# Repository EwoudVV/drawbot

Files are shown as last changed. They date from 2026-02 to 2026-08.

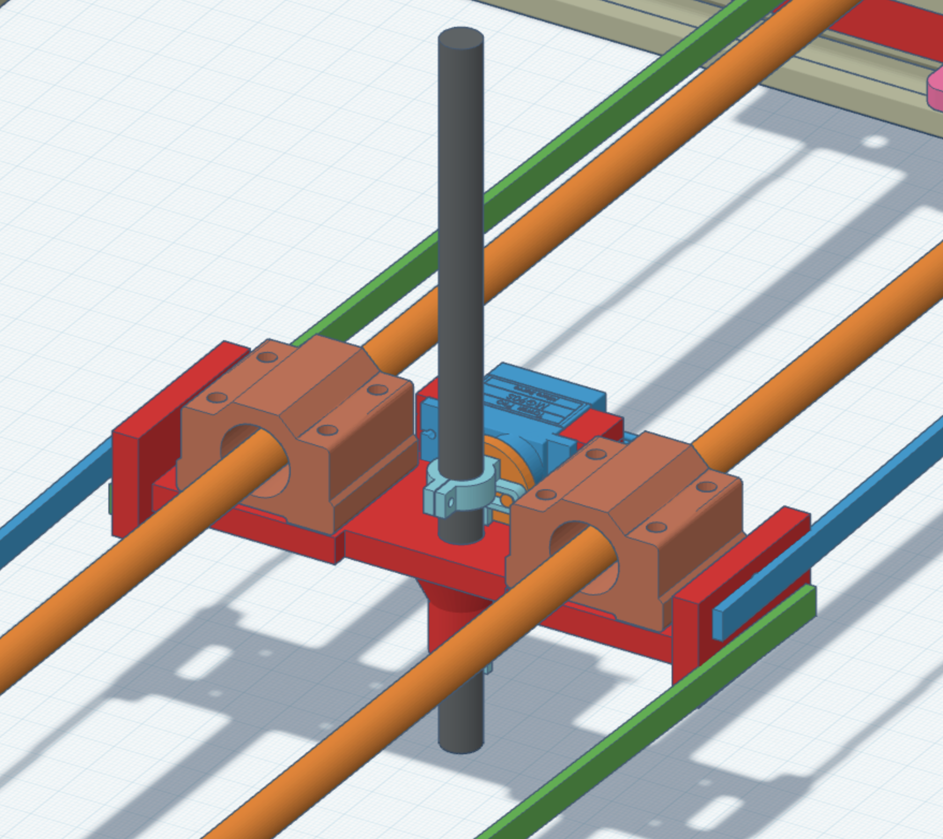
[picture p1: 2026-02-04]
pictures/toolhead.png

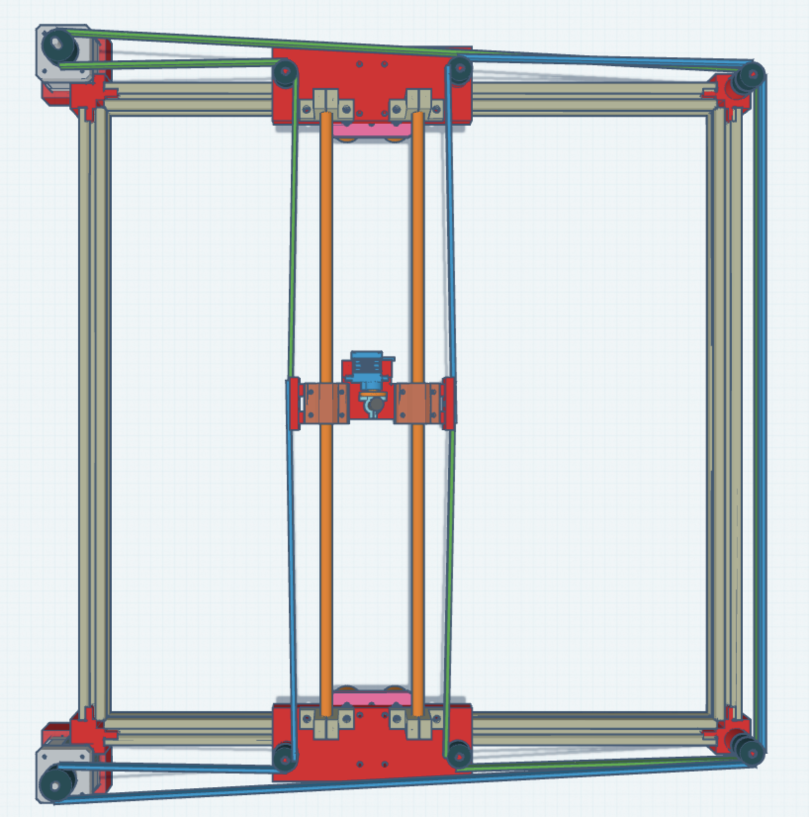
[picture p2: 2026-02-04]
pictures/topviewpersp.png

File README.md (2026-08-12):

## Drawbot

### Design: https://www.tinkercad.com/things/kSLyTMIcY53-drawbot

 - Made for [Hack Club Highway](https://highway.hackclub.com/)
 - This project is a 0.5 meter square drawing machine that I designed to be as fast and cheap as possible.
 - I made this project because I wanted to learn more about designing and using mechanisms, like the CoreXY belt design I used and the scotch-yoke mechanism used to lift the pen. I also wanted something functional, that I would use.

### Pictures



### Bill Of Materials

|Part |Qty|Price |Desc |Notes |Link |
|---|---|---|---|---|---|
|Arduino |1  |$29.30 |Uno R3 |not going to buy |http://store.arduino.cc/collections/boards-modules/products/arduino-uno-rev3 |
|Pen |60 |$7.99 |Bic Round Stic |not going to buy |https://us.bic.com/en_us/bic-round-stic-xtra-life-ball-point-pen-black-60-pack.html |
|500mm Aluminium Extrusion  |4  |$25.99 |500m V-slot aluminum extrusions |They come with extra accessories like connectors |https://www.amazon.com/Seekliny-Aluminum-Extrusion-V-Slotted-Accessories/dp/B0DY7FKXZ9/  |
|Linear Motion Rod Shaft |2  |$29.99 |Linear shaft for the toolhead to move on |Comes with bearings for the toolhead |https://www.amazon.com/uxcell-Bearing-Support-Automated-Machines/dp/B0CK4Z3M15 |
|Stepper Motor Nema 17 |2  |$25.99 |Motors to drive the gantry |High torque and high speed |https://www.amazon.com/Stepper-Motor-Bipolar-64oz-Printer/dp/B00PNEQI7W |
|Timing Belt |1  |$14.99 |5m belt |Extra accessories included like driver and idler wheels and belt clamps and tensioners|https://www.amazon.com/KeeYees-Timing-Tensioner-Torsion-Printer/dp/B07JKT5BZQ |
|Stepper Motor Driver Module|2  |$7.59 |Stepper motor drivers | |https://www.amazon.com/Stepper-Printer-StepStick-Envistia-Mall/dp/B07QT7N3T2 |
|Servo |1  |$2.99 |Fast servo that has metal gears and is small | |https://speedyfpv.com/products/mg90d-metal-digital-servo-new?variant=45194443030742 |
|Limit switches |2  |$5.56 |SS-5GL02 |For homing the toolhead |https://www.digikey.com/en/products/detail/omron-electronics-inc-emc-div/SS-5GL02/3102937|
|Roller plate |2  |$11.97 |Roller plates for attachment on the aluminum extrusions|Adjustable |https://www.amazon.com/QWORK-V-Wheel-Aluminum-Profile-Printer/dp/B0CHRYLV1V |
|Belt idler wheels |5  |$7.99 |Idler wheels for when the belt turns |4 extra are needed |https://www.amazon.com/Timing-Belt-Idler-Pulley-Printer/dp/B0BSPCHTD3 |
| | |SUBTOTAL: $133.06 |no extras | | |
| | |TOTAL: $141.38 |no extras and tax |assumes MA sales tax | |
| | |GRAND TOTAL: $170.35 |extras | | |
| | |GRAND GRAND TOTAL: $181.00|extras and tax |assumes MA sales tax | |

### Alternate BOM

|Part |Qty|Price |Desc |Notes |Link |
|---|---|---|---|---|---|
|Arduino |1  |$29.30 |Uno R3 |not going to buy | |
|Pen |60 |$7.99 |Bic Round Stic |not going to buy | |
|500mm Aluminium Extrusion  |4  |$25.99 |500m V-slot aluminum extrusions |They come with extra accessories like connectors |https://www.aliexpress.us/item/3256804642902887.html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 |
|Linear Motion Rod Shaft |2  |$17.64 |Linear shaft for the toolhead to move on | |https://www.aliexpress.us/item/2255800403003227.html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|
|Linear motion rod clamp |4  |$17.1 | | |https://www.aliexpress.us/item/2255799899348947.html?gatewayAdapt=glo2usa4itemAdapt |
|Linear bearings |2  |$13.27 | | |https://www.aliexpress.us/item/2251832487047487.html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 |
|Stepper Motor Nema 17 |2  |$15.22 |Motors to drive the gantry |High torque and high speed |https://www.aliexpress.us/item/2251832683239784.html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 |
|Timing Belt |1  |$9.35 |5m belt |Extra accessories included like driver and idler wheels and belt clamps and tensioners|https://www.aliexpress.us/item/3256803959490903.html?gatewayAdapt=glo2usa4itemAdapt |
|Stepper Motor Driver Module|2  |$10.55 |Stepper motor drivers | |https://www.aliexpress.us/item/2255800140733695.html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 |
|Servo |1  |$2.18 |Fast servo that has metal gears and is small | |https://www.aliexpress.us/item/3256806338932286.html?gatewayAdapt=glo2usa4itemAdapt |
|Limit switches |2  |$5.56 |SS-5GL02 |For homing the toolhead |https://www.digikey.com/en/products/detail/omron-electronics-inc-emc-div/SS-5GL02/3102937 |
|Roller plate |2  |$9 |Roller plates for attachment on the aluminum extrusions|NOT Adjustable |https://www.aliexpress.us/item/3256806120290201.html?gatewayAdapt=glo2usa4itemAdapt |
|Belt idler wheels |5  |$1.24 |Idler wheels for when the belt turns |4 extra are needed |https://www.aliexpress.us/item/2251832631013486.html?gatewayAdapt=glo2usa4itemAdapt |
| | |SUBTOTAL: $127.1|no extras | | |
| | |TOTAL: $135.05  |no extras and tax |assumes MA sales tax | |

### Software and documentation

 - The machine runs a custom Uno R4 WiFi + CNC Shield V3.00 firmware in [`code/drawbot_r4/`](code/drawbot_r4/) (compile, upload, and command docs in its README).
 - The machine is **commissioned and drawing**: scale verified, pen calibrated, and a 35-minute endurance run completed with zero errors. Because the bottom (Y-) limit switch is defective, the machine operates with **manual homing** (`M50 X0 Y0` after parking at the corner); `G28` will not complete until that switch is replaced.
 - Full operational history and debug findings live in [`docs/HANDOFF_V2.md`](docs/HANDOFF_V2.md) (supersedes [`docs/HANDOFF.md`](docs/HANDOFF.md)). Wiring and commissioning guides are in [`code/drawbot_r4/docs/`](code/drawbot_r4/docs/).
 - Presentation workflow: park at the corner, `M50 X0 Y0`, then `python3 code/drawbot_r4/tools/stream_gcode.py --ble code/drawbot_r4/examples/stress_30min.gcode`. Generate new hatch patterns with `tools/gen_stress_pattern.py --paper WxH`.

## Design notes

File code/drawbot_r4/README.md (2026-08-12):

# Uno R4 WiFi CoreXY Drawbot

This is a clean firmware rewrite for the 400 × 320 mm CoreXY drawing machine. It targets an Arduino Uno R4 WiFi with a Protoneer CNC Shield V3.00, two A4988 drivers, two normally-open home switches, and a scotch-yoke pen servo. It does not copy the old firmware.

Both A4988s have software-controlled MS1/MS2/MS3 inputs. Positions are always tracked in 1/16-step base units; each segment uses the coarsest compatible resolution from full through 1/16 without losing absolute position. Long straight drawing segments prefer coarse modes, while short curve/detail segments prefer fine modes.

Version 1 receives absolute, millimetre G-code over USB and BLE. The firmware advertises as "Drawbot" over Bluetooth LE using the standard Nordic UART Service (NUS). Pair from your Mac's Bluetooth settings or scan with `stream_gcode.py --ble`.

## Status: COMMISSIONED (2026-08-01)

- **The machine draws.** Verified end to end: 100 mm square, then a 35-minute
  endurance run (full-workspace hatching) with zero BLE drops or errors.
- **Pen is calibrated** (`PEN_CALIBRATED = true`): down = 500 µs (tip on
  paper), up = 1500 µs.
- **Scale verified**: `BASE_UNITS_PER_MM = 80.8` measured with a ruler.
- **Manual homing is the operating mode**: the bottom (Y−) limit switch is
  defective and never triggers, so `G28` will not complete. Park the carriage
  at the home corner, then send `M50 X0 Y0`.
- **Presentation workflow**: park at the corner, run
  `examples/stress_30min.gcode` (or any job) with
  `tools/stream_gcode.py --ble …`; the streamer auto-recovers from BLE drops
  with position reconciliation. Generate new hatch jobs with
  `tools/gen_stress_pattern.py --paper WxH`.

## Power and safety

Keep the 24→5 V buck converter. The Uno R4 must not power the servo, and 24 V
must not be connected to the Arduino 5 V rail. USB and 24 V must never be
applied at the same time: uploads are USB-only, motion is 24 V-only. Follow
[docs/WIRING.md](docs/WIRING.md) before applying power and
[docs/COMMISSIONING.md](docs/COMMISSIONING.md) before running `G28`.

## Build and upload

Install [Arduino CLI](https://arduino.github.io/arduino-cli/latest/installation/) or use Arduino IDE 2. Then install the official board core and required libraries:

```sh
arduino-cli core update-index
arduino-cli core install arduino:renesas_uno
arduino-cli lib install Servo
arduino-cli lib install ArduinoBLE
arduino-cli compile --fqbn arduino:renesas_uno:unor4wifi .
arduino-cli upload --fqbn arduino:renesas_uno:unor4wifi --port /dev/cu.usbmodemXXXX .
```

Open a 115200-baud serial terminal. The controller emits `ready` after boot. Every accepted command ends with `ok`; faults use `error: ...` and do not receive a trailing `ok`.

## Supported commands

| Command | Behaviour |
|---|---|
| `G21` | Select millimetres (the only supported unit) |
| `G90` | Select absolute positioning (the only supported mode) |
| `G0 X… Y… F…` | Raise the pen, then travel |
| `G1 X… Y… F…` | Coordinated line; preserves the explicit `M3`/`M5` pen state |
| `G28` | Home left, then bottom (blocked until the Y− switch is fixed) |
| `M3` / `M5` | Pen down / pen up |
| `M17` / `M18` | Enable / disable drivers; disabling invalidates homing |
| `M50 X… Y…` | Mark the current physical position and homed state (manual homing) |
| `M114` | Report position, homed state, and active microstep mode |
| `M119` | Report both home switches and the probe input |
| `M280 S…` | Send a bounded raw microsecond pulse for servo calibration |
| `M2` / `M30` | Pen up and disable the drivers (no auto-homing) |

Inches, relative positioning, arcs, unsupported words, multiple commands on one line, malformed numbers, and out-of-bounds targets are rejected. Soft limits are 0–400 mm X and 0–320 mm Y; targets are never silently clamped.
Travel feed is limited to 2000 mm/min and drawing feed to 800 mm/min; excessive `F` values are rejected rather than clamped.

## Stream a file

Dependencies are pre-installed in a Python venv. Use the wrapper:

```sh
tools/stream_gcode.sh --port /dev/cu.usbmodemXXXX examples/calibration_square.gcode
```

The sender waits for `ready`, sends one line, waits for `ok`, and stops immediately on the first firmware error. To stream over BLE instead of USB:

```sh
tools/stream_gcode.sh --ble examples/calibration_square.gcode
```

This scans for the "Drawbot" BLE peripheral, connects, and uses the same protocol over the Nordic UART Service.

## Project layout

- `config.h` — pins, calibration, feeds, limits, and safety bounds
- `corexy_math.h`, `dda_math.h`, `microstep_math.h` — portable CoreXY, coordinated-step, and safe mode-selection primitives
- `motion_controller.*` — acceleration, soft limits, switch monitoring, and homing
- `pen_controller.*` — servo control
- `gcode_parser.*`, `command_processor.*`, `serial_line_reader.*` — transport-independent command engine and USB framing
- `tests/` — native tests for transforms, DDA counts, parsing, limits, and interpolation

Run the portable tests with:

```sh
tests/run_tests.sh
```

## References

- [Arduino Uno R4 WiFi documentation](https://docs.arduino.cc/hardware/uno-r4-wifi/)
- [Uno R4 WiFi datasheet](https://docs.arduino.cc/resources/datasheets/ABX00087-datasheet.pdf)
- [Pololu A4988 carrier guidance](https://www.pololu.com/product/1182)
- [Protoneer CNC Shield V3 guide (archived mirror)](https://hexmix.ru/wp-content/uploads/2019/03/Arduino-CNC-Shield-V3.XX_.pdf)

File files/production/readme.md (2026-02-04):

Production files like print jobs go here

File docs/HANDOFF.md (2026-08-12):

# Drawbot Project — AI Handoff

> Comprehensive handoff for resuming this project in a fresh AI session.
> Read this first. Do not trust old KiCad notes or earlier diagnoses that have
> since been corrected (see "Lessons learned" below).

## Project location

```
/Users/ellievanvooren/Documents/codex/2026-06-19/i-have-a-drawing-machine-project/
```

The machine firmware is a single Arduino sketch under
`outputs/drawbot_r4/`. The machine is a CoreXY-style pen plotter built from
spare-parts steppers and 3D printer hardware, controlled by an Arduino Uno
R4 WiFi fitted with a Protoneer / GRBL 0.8-style CNC Shield V3.00 driving
two A4988 stepper drivers. G-code is sent over Bluetooth Low Energy (BLE)
using the Nordic UART service, with a chunked-println bridge that talks to
the Arduino USB serial.

Per-session directory naming is `<YYYY-MM-DD>/i-have-a-drawing-machine-project/`.
The `outputs/drawbot_r4/` tree is the working copy of the sketch and is
overwritten freely during work; the `work/` directory is a scratch area for
calibration artifacts and reference designs and should be treated as
read-only history.

## Anchored summary (the five facts the next agent must keep)

### Objective
- Get the CoreXY drawbot homing and drawing reliably over BLE.
- Stepping is now proven physically correct (motors lock, run, hit a wall,
  bounce off a limit switch). Remaining work: homing (`G28`), pen up/down
  calibration, end-to-end G-code streams from `examples/calibration_square.gcode`.

### Important details
- Power: **USB and 24 V cannot be applied simultaneously.** USB is used for
  sketch upload (24 V off); 24 V is applied for testing (USB off). Switching
  mid-test is fine but never overlap.
- **CNC Shield V3.00**, *not* the KiCad board that lived in the project
  earlier. The user explicitly told us to ignore the KiCad schematics as
  "very old" — the ENABLE-to-GND trace on the KiCad file is wrong for the
  current shield. Relevant shield fact: **D13 (MS3) is wired through R10
  into the A4988 RESET rail**, so any microstep mode with MS3 = LOW
  holds the drivers in reset. Only 1/16 stepping (MS1 = MS2 = MS3 = HIGH)
  keeps the drivers out of reset.
- **Uno R4 GPIO quirk**: `digitalWrite()` on a pin already in `OUTPUT`
  mode does not actually drive the pin. The reliable recipe is
  `digitalWrite(pin, val); pinMode(pin, OUTPUT);`. `digitalRead()` on the
  same pins returns the *logic level* correctly, so a `digitalRead`-based
  smoke test is misleading: it told us "the pins look right" while the
  motor wasn't actually getting current. The cure is always the
  `digitalWrite`-then-`pinMode` pair.
- The end-stop header is wired to `INPUT_PULLUP` and reads active **LOW**,
  so a pressed switch reads as `LOW`.
- `DRIVER_ENABLE_ACTIVE_LEVEL = HIGH` (D8 is inverted by the shield).
- Step timing is accurate on the R4. A requested 2 ms period measures
  ~2.094 ms, a 1 ms period measures ~1.050 ms, 500 µs measures ~528 µs,
  250 µs measures ~267 µs. The CPU is not the bottleneck.
- **Driver current**: VREF had been turned DOWN half a turn in an earlier
  session to "fix" a thermal shutdown that turned out to be a RESET-rail
  bug, not thermal. The lowered VREF left the A4988s unable to deliver
  enough current at higher step rates (NEMA 17 coil time constant is
  ~2 ms — at 4 kHz only ~12 % of the target current builds up in the
  coil). The user has since turned the trimpot back up by half a turn.
  **Target VREF is 0.9 – 1.1 V at the test point** (≈ 1.1 – 1.4 A with
  the 0.1 Ω sense resistors). Never push VREF past ~1.4 V.

### Work state
- **Done**: pin-driving recipe applied throughout `motion_controller.cpp`
  and both test commands; 1/16 microstep forced in `preferredMode()`,
  `home()`, and `homeAxis()` so MS3/D13 stays HIGH; `M100` rewritten as a
  raw step test with reported measured period; `M101` is the bare-pin
  smoke test (now also has limit-switch bounce); `M100` and `M101` both
  have the same limit-switch bounce protection (state-machine latch —
  see below); the sketch compiles clean (~100 kB / 38 % of flash).
- **Active**: the bounce latch in `M100` / `M101` was just updated from a
  naive per-step flip (which jittered at the lever) to a per-press latch
  that re-arms only after the switch reads open for 4 consecutive steps.
  The bounce test was interrupted before it could finish — the next agent
  should re-run the long BLE bounce test and confirm the gantry reverses
  cleanly without re-triggering.
- **Blocked / not yet verified**: `G28` homing, the full speed sweep
  (F500, F1000, F2000, F4000) without bumping a wall, the pen servo
  calibration (`M280`), and end-to-end runs of `examples/calibration_square.gcode`.

### Next move
1. Confirm the gantry is roughly centered (manually, with 24 V off).
2. Switch 24 V on, USB off, and run `M100 S16000 F2000` (≈ 20 s) over
   BLE. Expect: gantry moves until it hits a side, then reverses cleanly
   without rapid re-triggering, then hits the other side, then reverses
   again. Look for `limit bounce at step N` log lines.
3. Then `M100 S4000 F500` etc. to confirm the higher step rates work
   now that VREF is back up.
4. Once stepping is clean, run `G28` and confirm homing.
5. Then calibrate the pen with `M280`, and finally stream
   `examples/calibration_square.gcode`.

### Relevant files
- `outputs/drawbot_r4/drawbot_r4.ino` — main sketch, BLE init, BLE
  bridge, `BlePrint` chunked-flush wrapper.
- `outputs/drawbot_r4/config.h` — pin map, `DRIVER_ENABLE_ACTIVE_LEVEL`,
  `BASE_UNITS_PER_MM = 80.8`, feed-rate limits, switch active level,
  servo bounds.
- `outputs/drawbot_r4/command_processor.cpp` — M-code handlers,
  including `M100` and `M101` (raw step + bounce).
- `outputs/drawbot_r4/command_rules.h` — supported G/M codes whitelist.
- `outputs/drawbot_r4/motion_controller.cpp` — pin driving,
  microstep selection, homing.
- `outputs/drawbot_r4/gcode_parser.cpp` / `gcode_parser.h` — line parser.
- `outputs/drawbot_r4/microstep_math.h` — `MicrostepMode` and the
  `selectCompatibleMode` cascade.
- `outputs/drawbot_r4/tools/.venv` — Python virtualenv with `bleak` for
  BLE testing (Python 3.14).
- `outputs/drawbot_r4/tools/stream_gcode.py` and
  `outputs/drawbot_r4/tools/stream_gcode.sh` — file-streaming helpers.
- `outputs/drawbot_r4/examples/calibration_square.gcode` — the
  end-to-end test print.
- `outputs/drawbot_r4/docs/COMMISSIONING.md` and
  `outputs/drawbot_r4/docs/WIRING.md` — physical wiring reference.

## Hardware

### Controller
- **Arduino Uno R4 WiFi** (Renesas RA4M1). Has native BLE; the sketch
  uses the Arduino `BLEPeripheral` library that ships with the R4
  core. Build target: `arduino:renesas_uno:unor4wifi`.

### Stepper driver carrier
- **CNC Shield V3.00** (Protoneer / GRBL 0.8 layout). Sits on top of the
  Uno R4. Two A4988 stepper drivers in the X and Y sockets; the Z
  socket is unused. Z.STEP is rewired to a hobby servo on pin 4.
  Important wirings:
  - D8 → ENABLE, inverted on the shield (so `HIGH` enables).
  - D7 → MS1, D12 → MS2, D13 → MS3.
  - D13 feeds the A4988 RESET rail through R10 (100 Ω). This is the
    reason 1/16 microstepping is mandatory.
  - X socket = motor A (steps on D2, dir on D5).
  - Y socket = motor B (steps on D3, dir on D6).
  - End-stop headers: D9 = X, D10 = Y, D11 = Z/probe.

### Motors
- Two NEMA 17 steppers wired to A and B. Coil time constant ≈ 2 ms.
  1.8° / step (200 full steps / rev). At 1/16 microstepping the sketch
  uses 80.8 base units / mm (recovered from an old calibration).

### Power
- 24 V bench supply feeds the CNC shield VIN / motor rail. **Never apply
  USB and 24 V at the same time.** USB upload has 24 V off; 24 V testing
  has USB off. The Arduino is powered either by USB (upload) or by the
  shield's onboard 5 V regulator (BLE test), but never both rails at
  once.

### Trimpot
- Both A4988 modules have a small VREF trimpot. Target **0.9 – 1.1 V** at
  the test point; do **not** exceed ~1.4 V. The user turned it up half a
  turn from a too-low setting that had been chasing a misdiagnosed
  thermal shutdown.

### Limit switches
- Three mechanical switches on the end-stop header. Active LOW with
  `INPUT_PULLUP`. X switch on D9, Y switch on D10. The probe pin D11 is
  for the pen touch-probe, not for gantry limits.

## Firmware architecture

### Sketch structure
- `drawbot_r4.ino` — `setup()` initializes serial, BLE, the motion
  controller, and the pen. `loop()` reads serial lines, dispatches G/M
  commands through `CommandProcessor`, and writes responses back to
  serial. A `BlePrint` helper routes the same `Print` API the command
  handlers use out through BLE, chunked to fit MTU.
- `gcode_parser.{cpp,h}` — line-level parser, produces a `GCodeCommand`
  struct.
- `command_processor.{cpp,h}` — `handleGCode()` and `handleMCode()`
  dispatch tables. Uses a `requireNoArguments()` helper and a
  `setError()` helper to format error messages.
- `command_rules.h` — `isSupportedGCode()` / `isSupportedMCode()`.
- `motion_controller.{cpp,h}` — owns step generation. `begin()`,
  `enableDrivers()` / `disableDrivers()`, `setMicrostepMode()`,
  `setMotorDirections()`, `home()` (full G28), `homeAxis()` (single
  axis), `moveTo()` (queued via DDA-style ramp).
- `pen_controller.{cpp,h}` — servo control. `forceSafeUp()` raises the
  pen. `setAngle()` / `setPulse()` use the Arduino `Servo` library.
- `corexy_math.h`, `dda_math.h`, `microstep_math.h`,
  `workspace_math.h`, `machine_types.h` — math primitives.

### Supported G-codes
- `G0` / `G1` — linear move (rapid vs feed).
- `G21` — millimeters.
- `G28` — home all axes (implemented; not yet verified end-to-end).
- `G90` — absolute positioning.

### Supported M-codes
- `M2` / `M30` — pen up + home (used at end of program).
- `M3` / `M5` — pen down / pen up.
- `M17` / `M18` — enable / disable drivers.
- `M100` — raw step test. `S<steps>`, `F<period_us>` (default 2000),
  `X1` reverses both DIR pins, includes a limit-switch bounce latch.
- `M101` — bare-pin smoke test. `S<steps>` optional. Same bounce
  protection.
- `M114` — report current position.
- `M119` — report end-stop / probe state.
- `M280` — set servo pulse width (pen calibration).

### Test commands in detail

`M100 S<steps> [F<period_us>] [X1]`
- Enables drivers, drives both motors together (X-axis move).
- `F` is the step period in microseconds; clamped to ≥ 100 µs.
- Pulse HIGH for 50 µs, then LOW for `period_us − 50 µs`.
- `X1` starts in the reverse direction.
- On every step, polls `xHomeActive() || yHomeActive()`. If either is
  active and not already latched, flips both DIRs, latches, and prints
  `limit bounce at step N`. The latch stays engaged until the switch
  reads open for `kSwitchReleaseSteps = 4` consecutive steps, so the
  gantry always gets clear of the lever before re-arming. **Do not
  reimplement this as a "check + flip" pair** — that jittered at the
  switch because the gantry had not moved far enough to release it
  between the reverse and the next check.
- Reports `did N steps, requested P us, measured M us = X mm` using
  `micros()` for the wall-clock measurement.

`M101 [S<steps>]`
- Same as `M100` but no F / X / Y word support and the default step
  count is 400 at a fixed 2 ms period. Used as the "no-framework"
  smoke test when M100 misbehaves.

### Microstep mode handling
- `selectCompatibleMode()` cascades: if the requested mode is coarser
  than the driver can supply, it picks the next finer mode the driver
  actually supports. With `DRAW_*_STEP_MIN_MM` set so that even the
  finest motion wants 1/16, the cascade lands on 1/16 — which is
  *required* on this hardware to keep MS3 HIGH and RESET released.
- `home()` and `homeAxis()` explicitly call `setMicrostepMode(kSixteenth)`
  before seeking, so homing never accidentally drops MS3 LOW.

### Pin-driving convention (apply everywhere you touch a pin)
```cpp
digitalWrite(pin, value);
pinMode(pin, OUTPUT);
```
The order is mandatory on the R4. `pinMode(pin, OUTPUT)` first loses
the value on some peripheral mappings; `digitalWrite` alone on a pin
that is already OUTPUT does not re-drive it. The lambda `pi` inside
M100/M101 captures the pattern; in `motion_controller.cpp` it is
inlined into each method that touches a pin.

## BLE bridge

- The Arduino exposes a single Nordic UART service:
  - Service `6E400001-B5A3-F393-E0A9-E50E24DCCA9E`
  - TX characteristic `6E400002-...` (notify, Arduino → host)
  - RX characteristic `6E400003-...` (write, host → Arduino)
- Device name on macOS: `51974A51-AB5A-54FF-89A7-69167EA6986E`. The
  service UUID is what the host actually scans for; the device name is
  the one shown in the macOS Bluetooth menu.
- The Arduino `loop()` reads from `Serial` and writes to BLE; the
  `BlePrint` wrapper chunks the output into MTU-sized notifications
  with a small inter-chunk delay.
- Host-side test scripts live in `outputs/drawbot_r4/tools/.venv`
  (Python 3.14, `bleak`). Mac Bluetooth must be on or `bleak` will
  silently fail to enumerate. If the connection fails, check
  `System Settings → Bluetooth` first.
- The Python one-liner that has been used throughout the project:
  ```python
  import asyncio
  from bleak import BleakClient
  TXC='6E400002-B5A3-F393-E0A9-E50E24DCCA9E'
  RXC='6E400003-B5A3-F393-E0A9-E50E24DCCA9E'
  rec=b''
  def n(s,d):
      global rec; rec+=d
      while b'\n' in rec:
          l, rec = rec.split(b'\n',1)
          m = l.decode().strip()
          if m: print(f'< {m}')
  async def main():
      async with BleakClient('51974A51-AB5A-54FF-89A7-69167EA6986E', timeout=60) as c:
          await c.start_notify(TXC, n)
          await c.write_gatt_char(RXC, b'G28\n')
          await asyncio.sleep(30)
  asyncio.run(main())
  ```
- Long synchronous M-codes (anything that takes more than a few
  seconds) will exceed the macOS BLE supervision timeout and the
  connection will drop mid-run. **The command continues executing on
  the Arduino** — the drop only kills the notification stream. Reconnect
  afterward to query `M114` / `M119` for state. The Arduino does not
  need to be reset; the M-code is just running on the bare metal.

## Build, upload, and test commands

```sh
# Compile only
arduino-cli compile \
  --fqbn arduino:renesas_uno:unor4wifi \
  "/Users/ellievanvooren/Documents/codex/2026-06-19/i-have-a-drawing-machine-project/outputs/drawbot_r4/"

# Upload (24 V OFF, USB plugged in)
arduino-cli upload \
  --fqbn arduino:renesas_uno:unor4wifi \
  --port /dev/cu.usbmodemF412FA75568C2 \
  "/Users/ellievanvooren/Documents/codex/2026-06-19/i-have-a-drawing-machine-project/outputs/drawbot_r4/"

# BLE test (24 V ON, USB OFF)
/Users/ellievanvooren/Documents/codex/2026-06-19/i-have-a-drawing-machine-project/outputs/drawbot_r4/tools/.venv/bin/python \
  -c '... (one-liner above) ...'
```

Upload port: `/dev/cu.usbmodemF412FA75568C2`. The Arduino IDE also
recognizes the board under the same name.

## Lessons learned (do not re-learn these the hard way)

1. **The "thermal shutdown" was a RESET bug.** The Uno R4 was holding
   the A4988 RESET pin LOW because D13 / MS3 was being driven LOW by a
   microstep mode other than 1/16. The earlier fix idea — turning VREF
   *down* to keep the drivers cool — was wasted effort, and lowered
   the headroom we now need. VREF must stay around 0.9 – 1.1 V.
2. **`digitalRead` is not a motor-current probe.** A `digitalRead` can
   show the right level on a pin that the R4 is not actually driving
   hard enough to overcome the driver's input threshold. The
   `digitalWrite`-then-`pinMode` pair is the only known-reliable way to
   set an output on this board.
3. **A naive per-step limit-switch check will jitter.** The gantry
   needs time to move away from the lever after a bounce. Per-press
   latch + 4-step open-debounce is the minimum that works. A single
   "flip and continue" with no latch is worse than no bounce at all
   because it oscillates at the switch.
4. **The KiCad design is stale.** The current shield is a CNC Shield
   V3.00, *not* whatever the KiCad project shows. Anything in the
   KiCad files that conflicts with the live shield should be ignored.
5. **macOS BLE will drop a long-running connection.** That's fine —
   the Arduino keeps executing. Plan tests accordingly: short queries
   over BLE, long motions fire-and-forget, then reconnect.

## Open questions / known unknowns

- **VREF exact value.** The user turned the trimpot up by "half a turn"
  from the earlier too-low setting. The target is 0.9 – 1.1 V at the
  test point; we have not measured the actual value with a multimeter.
  Measuring it and recording the number is a good first step on the
  next session.
- **Switch polarity and "open" position.** The end-stop switches
  read `LOW` when pressed (active LOW, `INPUT_PULLUP`). We do not know
  which physical end (X+ or X−) the X switch sits at, and similarly for
  Y. The M100 bounce test will reveal this empirically: if the bounce
  sends the gantry in the wrong direction, the home switch is at the
  other end and we should still end up centered.
- **`G28` homing direction and seek distance.** The homing code uses
  `HOME_SEARCH_MARGIN_MM = 25 mm` and a final-release of 1 mm. The
  physical axis travel is 400 mm × 320 mm. The first G28 run after the
  bounce protection lands should be watched carefully: if the seek
  direction is wrong, the gantry will run to the opposite end of the
  axis. The bounce latch will eventually catch it, but it is better
  to verify the seek direction in `homeAxis()` first.
- **Pen calibration.** `PEN_CALIBRATED = false`; the safe-up /
  safe-down bounds are guessed. M280 is the way to find the real
  numbers.
- **Acceleration and feed rates.** `ACCELERATION_MM_S2 = 200` and
  `TRAVEL_FEED_MM_MIN = 2000` are starting points. They have not been
  tuned against the now-correct VREF; the gantry may be able to take a
  higher travel feed now.
- **`selectCompatibleMode` cascade.** The cascade goes finer-than, not
  coarser-than, which is what we want for keeping MS3 HIGH. But it
  means a future change to the feed-rate logic that asks for full-step
  motion will silently upgrade to 1/16. If that ever matters, re-read
  `microstep_math.h` before assuming a mode change took effect.

## Suggested next session plan

1. Re-read this file and the anchored summary.
2. With 24 V off, manually center the gantry on both axes.
3. Switch 24 V on, run `M119` over BLE to confirm the switch state
   baseline.
4. Run `M100 S16000 F2000` and watch for `limit bounce at step N`
   lines; confirm the gantry oscillates between both ends without
   jittering.
5. Run the speed sweep `M100 S1600 F500 / F1000 / F2000 / F4000`,
   alternating directions so the gantry stays roughly centered.
6. Verify the measured step period matches the requested one
   (look at the `measured M us` line).
7. If everything looks good, run `G28`. Watch the seek direction on
   both axes; if either runs the wrong way, the limit switch is at the
   opposite end of travel from what `homeAxis()` assumed.
8. Once `G28` is happy, use `M280` to find the pen up / pen down
   pulses, then update `config.h` and set `PEN_CALIBRATED = true`.
9. Finally stream `examples/calibration_square.gcode` and watch the
   first plot.

If the gantry still cannot move at the higher step rates after the
VREF bump, measure VREF with a multimeter; if it is below 0.9 V,
turn the trimpot up another small amount and retry. If it is already
at or above 0.9 V, the issue is mechanical (belt tension, pulley
eccentricity, or motor current limit) rather than electrical.

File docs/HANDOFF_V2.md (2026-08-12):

# Drawbot — Handoff V2 (motor/direction debug)

## Handoff V4 addendum (same-day commissioning results)

> The machine was **commissioned to the point of drawing** on 2026-08-01,
> operating by manual homing. Read this before the V3 addendum.

### Verified working (end to end, on hardware)
- ENABLE polarity: `DRIVER_ENABLE_ACTIVE_LEVEL = LOW` (D8 direct, active-low).
- Direction reversal (dir HIGH=right, LOW=left), bounce logic on the X switch.
- CoreXY Y-sign convention corrected in `corexy_math.h` (A advances X−Y,
  B advances X+Y on THIS machine) + `stepHomingAxis`; host tests updated.
- Pen servo calibrated: down=500 us (tip touches paper), up=1500 us.
  `PEN_CALIBRATED = true`, `SERVO_SAFE_MIN_US = 500`. Servo floor was 700 —
  the pen could not reach the paper; the holder was also adjusted.
- Scale: `BASE_UNITS_PER_MM = 80.8` verified by a 100 mm dot-to-dot ruler
  measurement. Microstepping confirmed effectively 1/16 by correct distance.
- Manual homing path: `M50 X<mm> Y<mm>` sets position + marks homed (added
  this session; no motion). G0/G1/M3/M5 now all work after M50.
- `M2`/`M30` no longer auto-home (would ram the dead Y switch); they raise
  the pen and disable drivers.
- 100 mm square drawn over BLE via `stream_gcode.py` (`square_manual.gcode`)
  — all commands ok, square verified by eye. **The machine draws.**
- `stream_gcode.py` fixed (missing `bleak.` prefix; BLEDevice details;
  "ready" wait now tolerant of already-running boards). `servo_sweep.py`
  added (BLE pulse sweeps, floor 500).

### Still open
- **Bottom (Y−) limit switch never triggers on ANY header**, while the
  switch's own continuity is perfect (open=1, closed=0 at its plug) and a
  known-good switch triggers on the same headers. All other links proven
  fine; the fault is confined to the switch's plug/header contact pair —
  unresolved, operator chose manual homing for now. G28 will keep failing
  until it is fixed (reterminate the plug or solder it directly).
- `tools/servo_sweep.py --range` argument parsing is broken; pass explicit
  value lists instead.
- Endurance run (30 min) not yet done. Home switches still pressed into
  wrong walls not re-checked; probe button never verified.

### Standard startup procedure (manual homing)
1. 24 V on, BLE: `M18` (release), push gantry to corner, `M50 X0 Y0`.
2. Verify `M114` → homed:yes. Load paper, `M3`/`M5` spot-checks.
3. Stream gcode with `stream_gcode.py --ble` or `ble_test.py fire` for
   single commands. Finish with `M2` (pen up, motors off).

---

## Handoff V3 addendum (same day, after the shield-polarity research)

> Read this first. It resolves the two "suspect, must re-verify" claims in
> V2 below and documents the firmware fix + the new incremental probe tool.

### What was resolved (2026-08-01, schematic + grbl 0.8 + empirical evidence)

1. **ENABLE polarity: D8 is ACTIVE-LOW, direct, no inverter.** On the
   official Protoneer CNC Shield V3.00 design, D8 is the common A4988
   ENABLE net, connected directly to all driver sockets, with R1 (10K)
   pulling it to 5 V (so the net idles high = drivers off). grbl 0.8 —
   which the shield is built for — writes D8 **LOW to enable**
   (`st_wake_up`) and HIGH to disable (`st_go_idle`, `$15=0`). This
   matches the empirical evidence exactly: old firmware left D8 LOW and
   the machine moved; the pinMode-first fix wrote D8 HIGH and the motors
   went completely dead.
2. **The "D13 → R10 → A4988 RESET rail" claim is REFUTED.** The official
   V3.00 design contains no such connection and no R10 (the only
   resistor is R1). D12/D13 are the SpnEn/SpnDir headers. MS pins cannot
   disable the drivers — they only select stepping resolution. A4988
   RESET floats on the shield; the carrier's SLEEP internal pull-up
   keeps the drivers running.
3. Therefore the V2 worry "one of those HIGHs kills the drivers" is
   answered: it was ENABLE (D8 HIGH), and nothing else. The regression
   was purely `DRIVER_ENABLE_ACTIVE_LEVEL = HIGH` in config.h plus
   hardcoded HIGH in M100/M101.

### Changes made this session (all compile clean, 100 864 B / 38 % flash)

- `config.h` — `DRIVER_ENABLE_ACTIVE_LEVEL = LOW`, with a comment citing
  the verified facts. This restores motion.
- `command_processor.cpp` — M100/M101 now write
  `config::DRIVER_ENABLE_ACTIVE_LEVEL` to D8 instead of hardcoded HIGH;
  the "inverter" comments are gone.
- `motion_controller.cpp` — stale RESET-rail/1/16-mandatory comments in
  `preferredMode()`, `homeAxis()`, `home()` replaced with the real
  rationale (1/16 base units, 80.8 units/mm calibration).
- `tools/driver_state_probe/driver_state_probe.ino` — NEW incremental
  probe (BLE + USB Serial, menu commands, see below). Compiles to
  86 080 B.

### What still needs physical verification (in order, hand on the 24 V cutoff)

1. Upload (USB only, 24 V off), then 24 V on.
2. **ENABLE lock check:** over BLE send `M17` → motors should LOCK
   (holding torque). `M18` → release. Alternative/fallback: flash the
   probe sketch, send `?` then `E0` (enabled) / `E1` (off).
   If no lock, measure D8 vs the driver ENABLE pins with a multimeter:
   expect D8 LOW ⇔ ENABLE LOW with no inversion.
3. **Direction reversal (the original bug):** gantry mid-travel, clear of
   switches: `M100 S200 F2000` (dir HIGH) — note travel direction; then
   `M100 S200 F2000 X1` (dir LOW) — must travel the opposite way. Then
   the bounce test near a wall: `M100 S4000 F2000` — the gantry must
   reverse off the wall (look for "limit bounce at step N"). Then the
   full `M100 S40000 F2000`.
   Probe alternative: `D1`, `S200`, `D0`, `S200` — the machine must
   reverse between the two bursts.
4. **Microstepping** (only affects distance, not motion): with a
   multimeter on the MS pads, `M111` in the probe should show 1/16 on
   the actual MS1/2/3 pins. If the D7/D12/D13 mod wires are missing,
   the machine runs full-step and moves 16× too far per unit — do NOT
   conclude the driver is broken; re-check BASE_UNITS_PER_MM after the
   mod wiring is confirmed.
5. Record the actual VREF at the trimpots (keep ≤ ~1.4 V). Then G28,
   M280 pen calibration, square.

### Probe sketch usage

```sh
arduino-cli compile --fqbn arduino:renesas_uno:unor4wifi outputs/drawbot_r4/tools/driver_state_probe/
arduino-cli upload --fqbn arduino:renesas_uno:unor4wifi \
  --port /dev/cu.usbmodemF412FA75568C2 outputs/drawbot_r4/tools/driver_state_probe/
tools/.venv/bin/python tools/ble_test.py send "?"   # or E0 / M7 / D0 / S200 / R
```

Commands: `?` report | `E0/E1` enable (E0 = enabled, active-low) |
`M0..M7` MS bits (M7 = 1/16) | `D0/D1` both DIR | `A0/A1`, `B0/B1`
per-motor DIR | `S[n]`, `SA[n]`, `SB[n]` step bursts (default 400,
2 ms period) | `R` reset (drivers off) | `H` help. Boot state is safe
(ENABLE high, drivers off). Also accepts USB Serial input when 24 V is
off (multimeter level checks).

### Standing notes for the next AI

- The V2 sections below remain accurate except where this addendum
  disagrees (ENABLE polarity, R10/RESET rail, "1/16 mandatory").
- The pin write-order discovery in V2 is still the single most
  important Uno R4 fact: `pinMode(OUTPUT)` resets the output data
  register — always write pinMode FIRST.
- `HOME_SEARCH_MARGIN_MM`, `MOTOR_*_DIRECTION_INVERTED`, homing
  end-to-end, and the 80.8 units/mm calibration all remain unverified
  until the machine moves both ways.

---

## Handoff V2 body (original; see addendum above for the resolved claims)

> Written 2026-08-01 after a session where the root cause of the "never
> reverses" bug was found and *partially* fixed — the fix then exposed that
> more shield-polarity assumptions are wrong. **Read this entire file before
> touching anything.** It supersedes `HANDOFF.md` on every point where they
> disagree. The old file is still the reference for BLE/architecture/commands.

## Critical status (what a new AI must know first)

1. **The machine currently does not move at all.** With 24 V applied, the
   motors are not even locked (no holding torque). The previously-flashed
   firmware ran the motors but they **never changed direction** (gantry
   rammed into the wall, bounce logic fired, motors kept pushing).
2. **The handoff's "digitalWrite-then-pinMode" pin recipe is PROVEN WRONG**
   by an on-device probe (see below). The correct order on this Uno R4 core
   is `pinMode(pin, OUTPUT); digitalWrite(pin, val);`.
3. **Several shield-polarity claims in the old handoff are now suspect and
   must be re-verified with a multimeter, not assumed.**
4. The limit switches, BLE link, bounce logic, and switch detection all
   **work**. The problem is 100 % in the motor/direction/enable path.
5. Do **not** run any long motion test until the ENABLE/MS polarity is
   determined incrementally (test plan at the end).

---

## The one verified discovery: pin write order on the Uno R4

A probe sketch (`outputs/drawbot_r4/tools/pin_probe/pin_probe.ino`) writes
each pin with three sequences and reads it back. Run on the actual board,
actual core (`arduino:renesas_uno:unor4wifi`, core 1.6.0). Results, for
every pin tested (2, 3, 5, 6, 7, 12, 13) — identical on all of them:

| Sequence | Result |
|---|---|
| `digitalWrite(pin, HIGH); pinMode(pin, OUTPUT);` | pin ends **LOW** |
| `pinMode(pin, OUTPUT); digitalWrite(pin, HIGH);` | pin ends **HIGH** |
| `pinMode(pin, OUTPUT);` then plain `digitalWrite(pin, HIGH)` | pin ends **HIGH** |
| `digitalWrite(pin, HIGH); pinMode(OUTPUT);` then `digitalWrite(pin, LOW)` … | **LOW, and then LOW again — it cannot be re-raised via the recipe** |
| plain `digitalWrite` toggling on an already-OUTPUT pin | works correctly |

So `pinMode(OUTPUT)` **resets the output data register to 0**, clobbering
any value written before it. `R_IOPORT_PinCfg(OUTPUT)` in the core
(`cores/arduino/digital.cpp`) is what does it. The old handoff's lesson
"digitalWrite alone on an OUTPUT pin doesn't drive it — use
digitalWrite-then-pinMode" is **backwards and was itself a misdiagnosis**
(same family as the "thermal shutdown" red herring).

### Why the old firmware "moved but never reversed"

The old code everywhere used `digitalWrite(val); pinMode(OUTPUT);` → every
write collapsed to LOW:

- **DIR pins (D5/D6): always LOW** → direction could never change. The
  bounce latch ran (we saw `limit bounce at step N` prints) but the motors
  were told to go the same way every time → ramming.
- **MS1/MS2/MS3 (D7/D12/D13): always LOW** → machine was actually running
  in **full-step**, not 1/16, regardless of all the `kSixteenth` code.
- **ENABLE (D8): always LOW** → and the machine still moved → **D8 LOW
  evidently leaves the drivers enabled on this board** (see polarity
  question below — this contradicts the old handoff).
- **STEP pins (D2/D3): toggled in the loop with plain `digitalWrite`**
  (no `pinMode` re-call) → **worked fine** → motors stepped. This is why
  "stepping worked" while "direction never worked".

---

## Session timeline (what was observed, in order)

1. Over USB: switches verified — `M119` shows `x_home`/`y_home` flipping
   independently when pressed, probe stays `open`. Both switches and the
   bounce latch logic are fine. (tool: `tools/switch_test.py`)
2. Over BLE, 24 V on: `M100 S40000 F2000` (new telemetry build) showed the
   bounce latch firing repeatedly — `limit bounce at step 918`, then
   `x:TRIGGERED y:TRIGGERED` a second later — but the gantry stayed pressed
   into the wall/corner and kept re-triggering. Motors never reversed.
3. User manually pressed switches during a run: **motors did not change
   direction.** Confirmed: not a switch problem.
4. Pin probe (above) → discovered the write-order bug.
5. Fixed the order in `command_processor.cpp` (M100/M101 `pi`/`setDirs`) and
   `motion_controller.cpp` (`begin`, `enableDrivers`, `disableDrivers`,
   `setMicrostepMode`, `setMotorDirections`) → compiled → uploaded.
6. **Regression:** now with 24 V on, `M100 S40000 F2000` runs (progress
   lines stream) but the motors do not move at all — not even locked.

## Why the fix made it worse (analysis, still to be verified)

The fix changed five pin groups from LOW to their *intended* values:
MS1/2/3 HIGH, ENABLE HIGH, DIR HIGH. One of those HIGHs kills the drivers.
Two candidates, in order of likelihood:

1. **ENABLE (D8) polarity is active-LOW in practice.** Old state (D8 LOW)
   = drivers enabled → machine moved. New state (D8 HIGH) = drivers
   disabled → no current, no lock, no motion. This fits "not even locked"
   perfectly. The old handoff claimed "D8 → ENABLE, inverted on the shield
   (so HIGH enables)" — **this claim is now contradicted and must be
   re-verified on the actual board** (the shield may not invert D8, or D8
   may not even reach the driver ENABLE pins).
2. **The "D13 → R10 → A4988 RESET rail" claim may be wrong.** If that
   claim were true, the old code (MS3 clobbered LOW) would have held the
   drivers in RESET — yet the machine moved. So either the R10 rail is not
   RESET, is disconnected, or has inverse polarity. Driving MS3 HIGH may
   then be *asserting* something that disables the drivers.

Both are examples of why: **the shield's enable/reset/microstep polarity
must be measured, not assumed.**

---

## What is verified vs. suspect

### Verified (this session, on this hardware)
- Switch wiring/readback: active LOW via `INPUT_PULLUP`, `M119` correct.
- BLE Nordic UART bridge works; long runs drop the link (expected); board
  keeps executing; reconnect works.
- The pin write-order behavior in the table above (all tested pins).
- With old clobbered-to-LOW firmware: motors step, machine moves in one
  direction, never reverses, ramps against the wall.
- With new pinMode-first firmware: motors completely dead (no lock).
- M100/M101 bounce latch + telemetry prints + BLE polling during loops
  (progress every 512 steps, switch-state changes, `output.flush()` in
  loop) — all work.

### Suspect (old handoff claims now contradicted)
- "D8 → ENABLE, inverted so HIGH enables" — likely wrong (see above).
- "D13 → R10 → RESET rail; only 1/16 (MS3 HIGH) releases RESET" — at least
  incomplete; old code ran with MS3 LOW.
- "Only 1/16 stepping works" — old code ran fine in full-step.
- "VREF must be 0.9–1.1 V" — may still be fine, but it was tuned while
  chasing the same misdiagnosis family. Verify with multimeter, don't trust.

### Known-good from old handoff (still valid)
- BLE architecture, UUIDs, device address, chunked-println bridge.
- Command set (G0/G1/G21/G28/G90, M2/M3/M5/M17/M18/M100/M101/M114/M119/M280).
- Power rules (USB vs 24 V never simultaneously), VREF range as a *bound*
  (do not exceed ~1.4 V), motors NEMA 17, CoreXY kinematics, 80.8 base
  units/mm at 1/16.
- CNC Shield V3.00 basics: X socket D2/D5, Y socket D3/D6, end stops
  D9/D10/D11.

---

## Current firmware state (what the next AI inherits)

Files changed today (all compile clean, 100.8 kB / 38 % flash):

- `outputs/drawbot_r4/command_processor.cpp` — M100/M101: `pi`/`p`/`setDirs`
  lambdas now `pinMode` first, then `digitalWrite`. Plus new live telemetry:
  switch-state change prints, `limit bounce at step N`, progress every 512
  steps, `output.flush()` after prints, `motion_.pumpIdle()` every step.
- `outputs/drawbot_r4/motion_controller.cpp` — same pinMode-first order in
  `begin()`, `enableDrivers()`, `disableDrivers()`, `setMicrostepMode()`,
  `setMotorDirections()`.
- `outputs/drawbot_r4/motion_controller.h` — added `pumpIdle()`.
- `tools/pin_probe/pin_probe.ino` — the probe (compiles for
  `arduino:renesas_uno:unor4wifi`; prints results continuously in `loop()`).
- `tools/ble_test.py`, `tools/switch_test.py` — BLE/switch test harnesses.

**To restore "machine moves (but never reverses)":** revert the write order
to `digitalWrite` then `pinMode` in `setDirs`/`pi`/`p` (M100/M101) and in
`motion_controller.cpp`. **Do not do this as a fix** — it is only a
diagnostic baseline; it cannot reverse direction.

## The test plan for the next AI (do this before any long motion test)

Goal: determine, one pin group at a time, what actually drives the A4988s.

1. **Measure, don't guess.** With 24 V on and motors unplugged (or plug
   into the driver sockets on the shield with a voltmeter):
   - D8 level vs. driver ENABLE pin level — is there an inverter? Which
     D8 level gives ENABLE low (enabled)?
   - D13/D12/D7 vs. MS1/MS2/MS3 pins — which net is which?
   - D13 vs. the A4988 RESET/SLEEP pins — does R10 actually connect, and
     to what? (RESET is active-low: released = HIGH.)
   - Measure the actual VREF at the trimpot test point and record it.
2. **Extend the pin probe** (or write a new one) to hold each combination
   of ENABLE/MS and verify the motors lock (with 24 V on, small current):
   - Find the ENABLE polarity that locks the motors (try D8 HIGH vs LOW
     with MS pins fixed).
   - Find which MS level combination keeps them out of reset.
3. **Verify direction.** Drive DIR high vs low with a slow fixed step burst
   (e.g. 200 steps, 10 ms period) and confirm the gantry actually reverses
   when DIR changes. This is the bug that started everything.
4. Only after direction reversal works: re-run the M100 bounce test over
   BLE (`M100 S4000 F2000` from near a wall, or the full
   `M100 S40000 F2000`), then G28, then pen calibration, then the square.
5. Then decide the correct `config.h` values: `DRIVER_ENABLE_ACTIVE_LEVEL`,
   `MOTOR_A/B_DIRECTION_INVERTED`, and whether 1/16 microstepping is
   actually required or was another artifact of the same misdiagnosis.

## Safety rules (unchanged, still binding)

- USB and 24 V must never be applied simultaneously. Upload = USB only,
  24 V off. Motion tests = 24 V only, USB off.
- Hand near the 24 V cutoff during any motion test.
- VREF: keep at/below ~1.4 V at the test point. Prefer ~1 A/phase.
- Unplug a stepper only with driver power off.
- Do not run long ramming tests; the gantry CANNOT reverse until the
  direction issue is fixed.

## Open questions for the next AI

- Actual ENABLE polarity / whether D8 reaches ENABLE at all.
- Actual MS1/2/3 routing and whether 1/16 is needed (old code ran full-step
  fine — maybe the "1/16 mandatory" was wrong).
- Actual VREF measurement (record it).
- Which physical end each switch is at (X+/X−), and DIR polarity mapping
  for homing — only discoverable after direction reversal works.
- `HOME_SEARCH_MARGIN_MM`, `MOTOR_*_DIRECTION_INVERTED`, and the whole
  homing sequence still unverified end-to-end.

## Build/upload/test commands (same as before)

```sh
arduino-cli compile --fqbn arduino:renesas_uno:unor4wifi outputs/drawbot_r4/
arduino-cli upload --fqbn arduino:renesas_uno:unor4wifi \
  --port /dev/cu.usbmodemF412FA75568C2 outputs/drawbot_r4/
tools/.venv/bin/python tools/ble_test.py send "M119"        # short query
tools/.venv/bin/python tools/ble_test.py fire "M100 S4000 F2000" --listen 30
tools/.venv/bin/python tools/switch_test.py --port /dev/cu.usbmodemF412FA75568C2
```

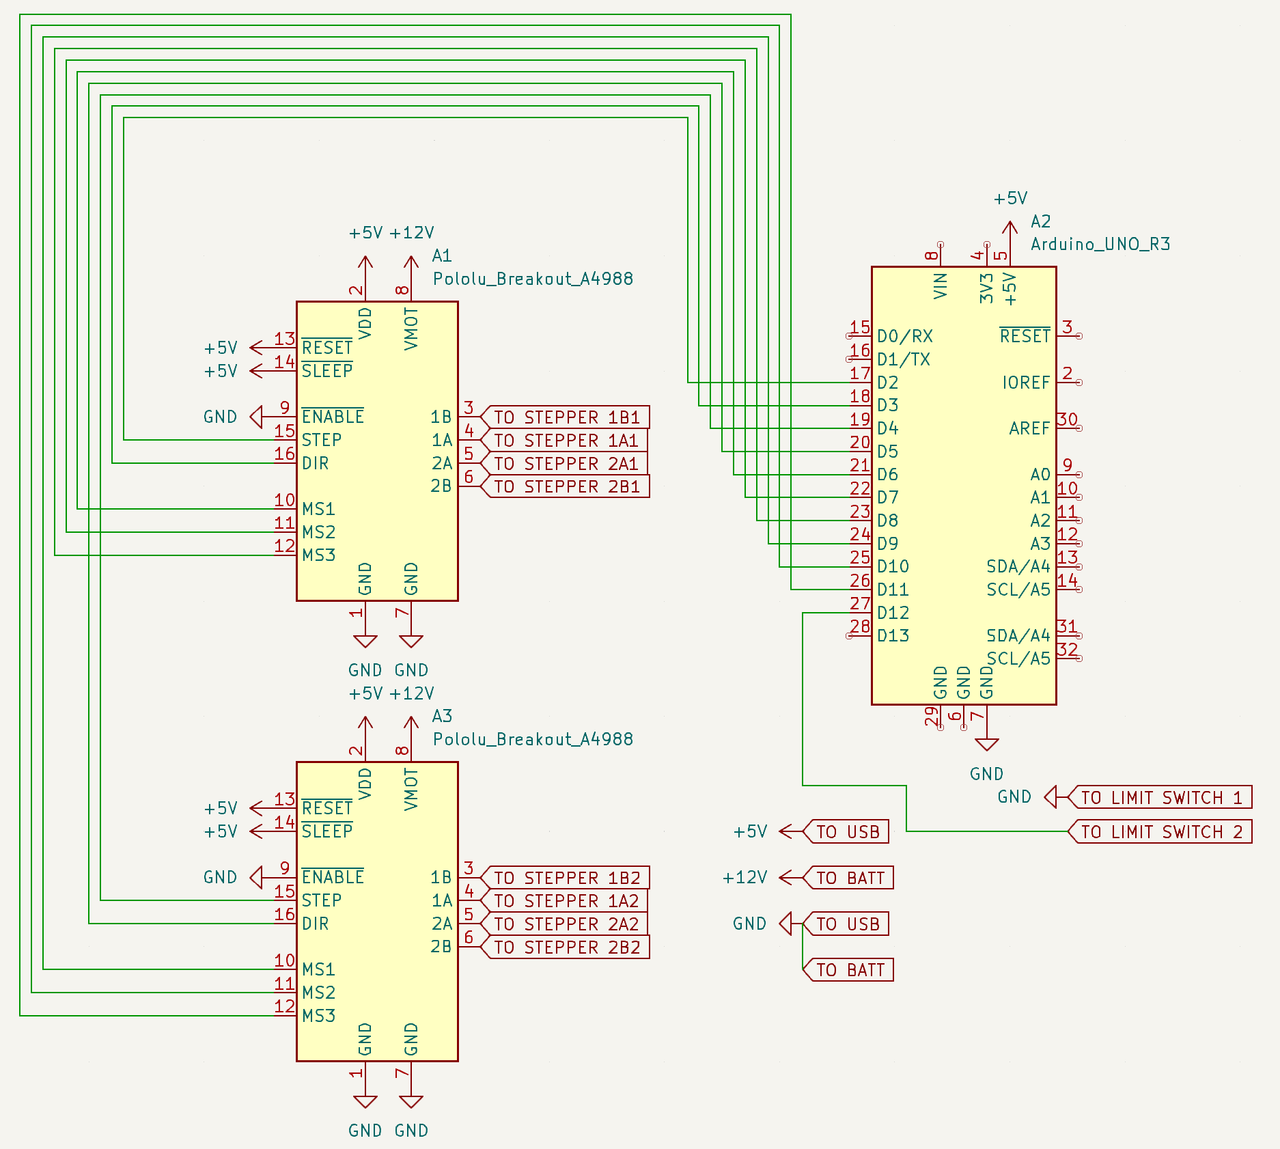
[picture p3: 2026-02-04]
pictures/schematic.png

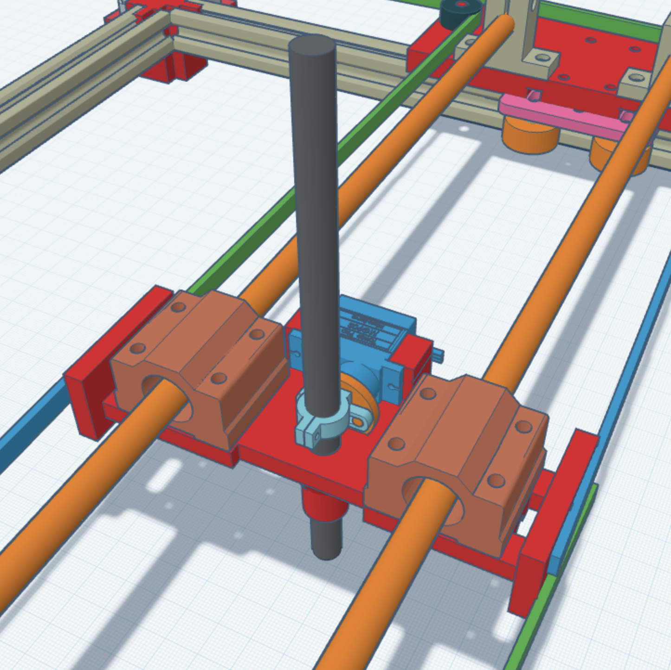
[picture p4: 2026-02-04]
pictures/toolheadpersp.png

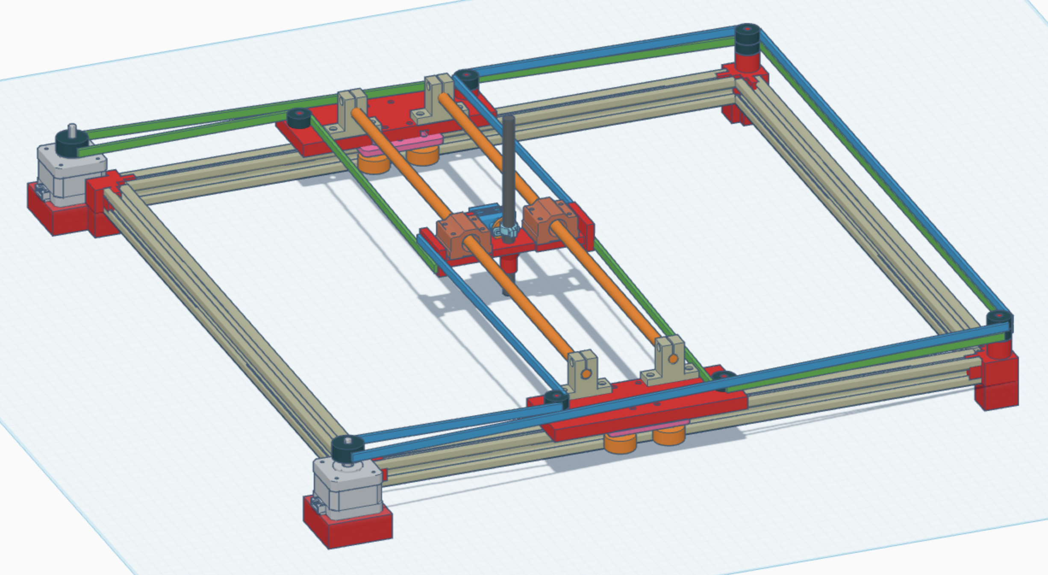
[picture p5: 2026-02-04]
pictures/all.png

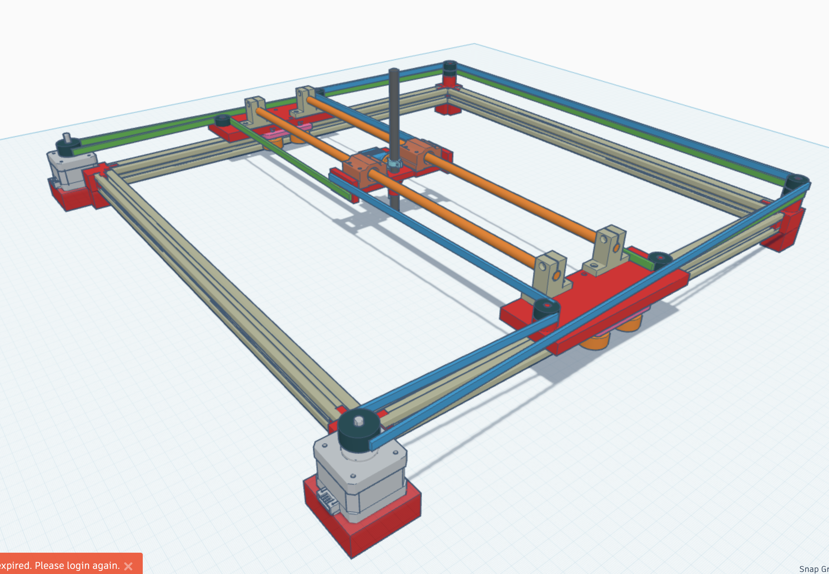
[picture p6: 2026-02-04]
pictures/allpersp.png

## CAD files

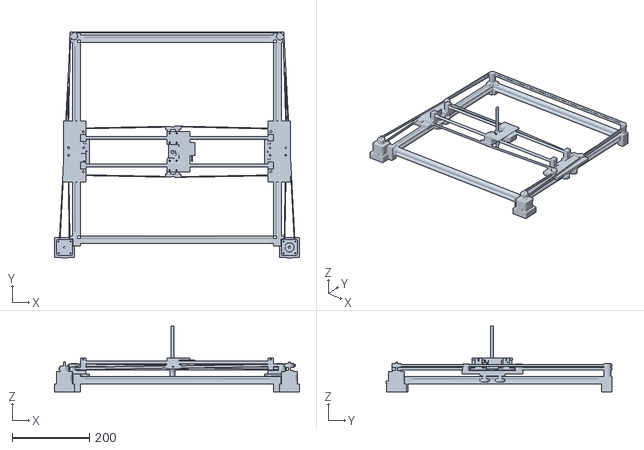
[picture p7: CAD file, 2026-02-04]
files/cad/drawbot_full.stl
634.0 x 584.0 x 170.0

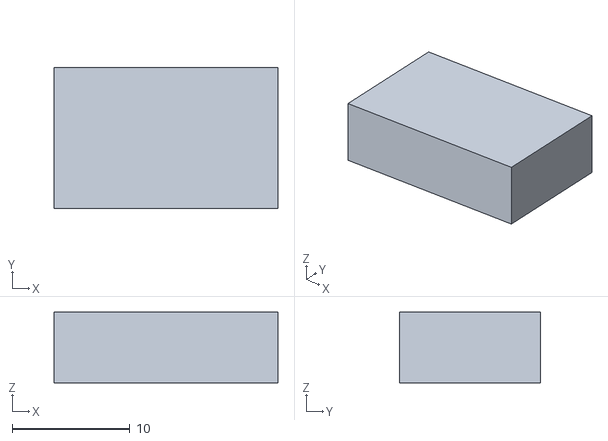
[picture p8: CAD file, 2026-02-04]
files/cad/drawbot_limitswitchspacer1.stl
19.0 x 12.0 x 6.00

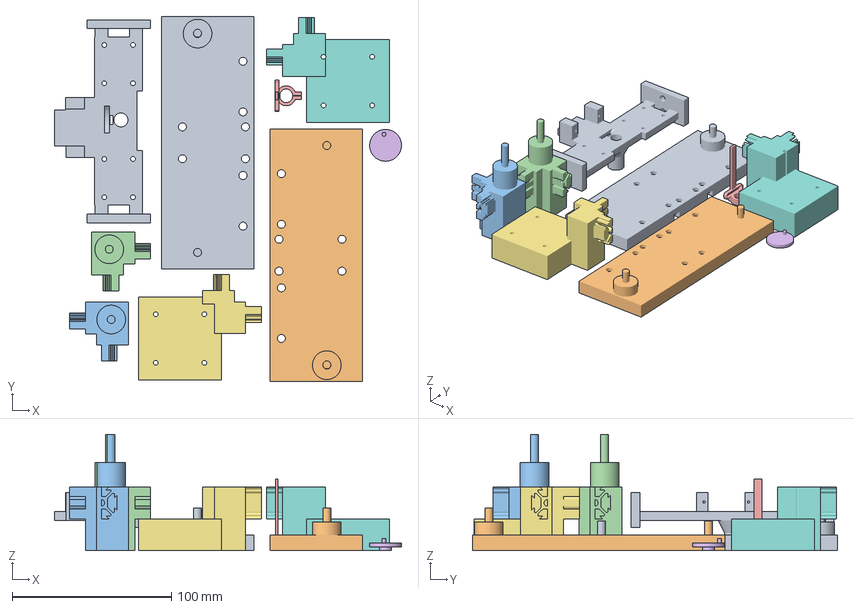
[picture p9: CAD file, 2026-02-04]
files/production/sliced.3mf
217.6 x 229.0 x 73.0 mm
gantrybase1.stl
gantrybase2.stl
idlercorner1.stl
idlercorner2.stl
penlift.stl
servohorn.stl
steppercorner1.stl
steppercorner2.stl
toolhead.stl

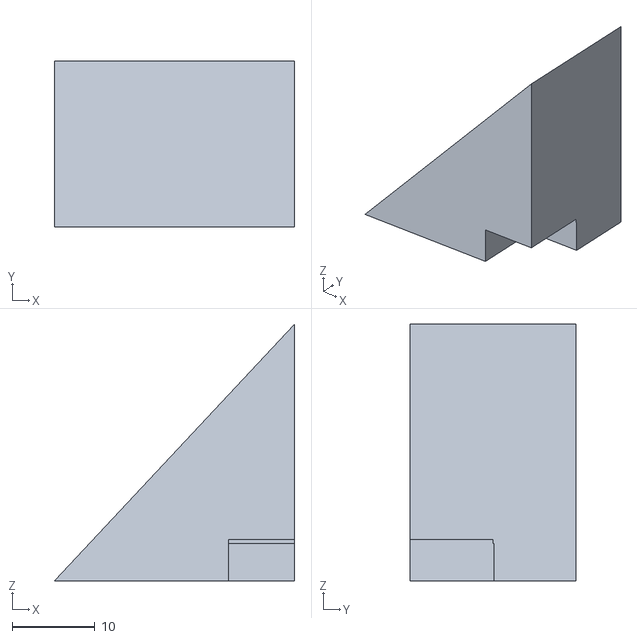
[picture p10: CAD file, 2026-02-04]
files/cad/drawbot_limitswitchstopper.stl
29.0 x 20.0 x 31.0

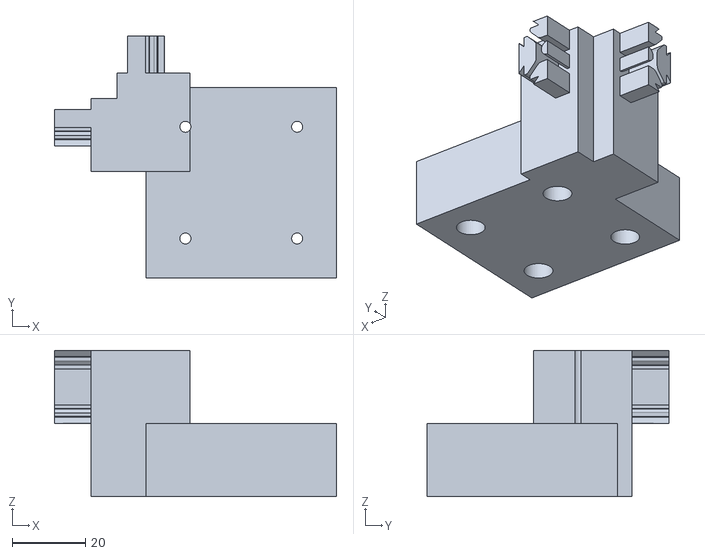
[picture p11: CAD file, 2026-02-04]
files/cad/drawbot (4).stl
77.0 x 66.0 x 40.0

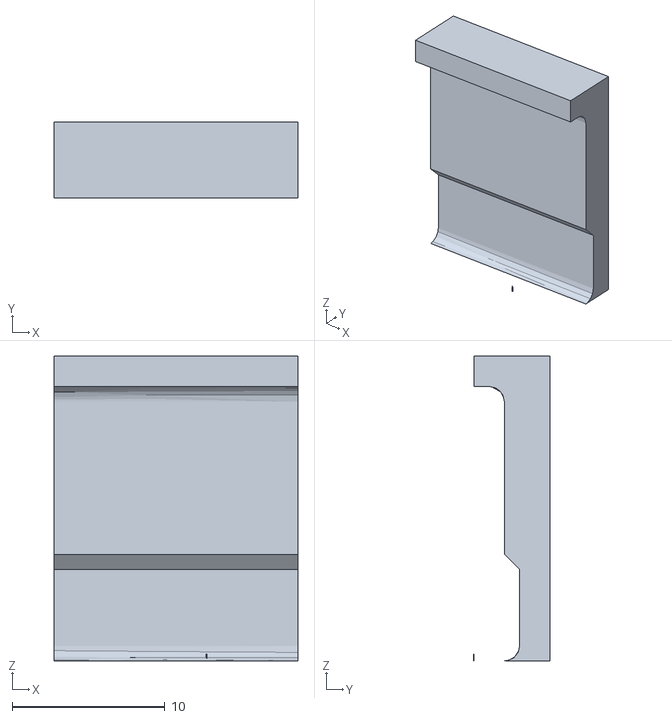
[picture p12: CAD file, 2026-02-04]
files/cad/drawbot_limitswitchspacer2.stl
16.0 x 5.00 x 20.0

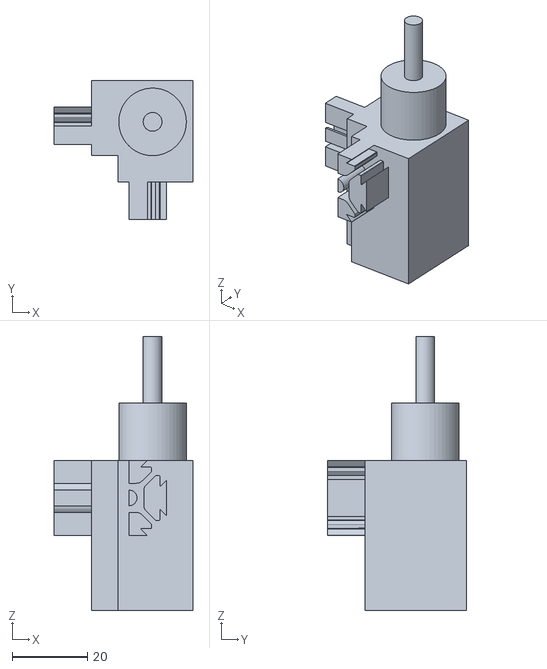
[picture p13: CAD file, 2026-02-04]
files/cad/drawbot_idlermount2.stl
37.0 x 37.0 x 73.0

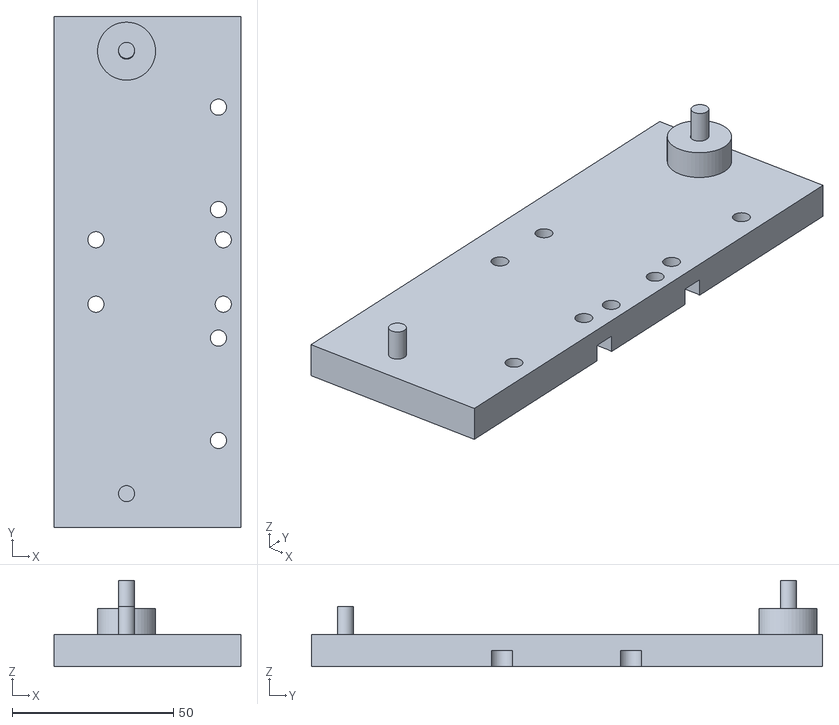
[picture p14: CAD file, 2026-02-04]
files/cad/drawbot_gantryplate2.stl
58.0 x 158.5 x 26.8

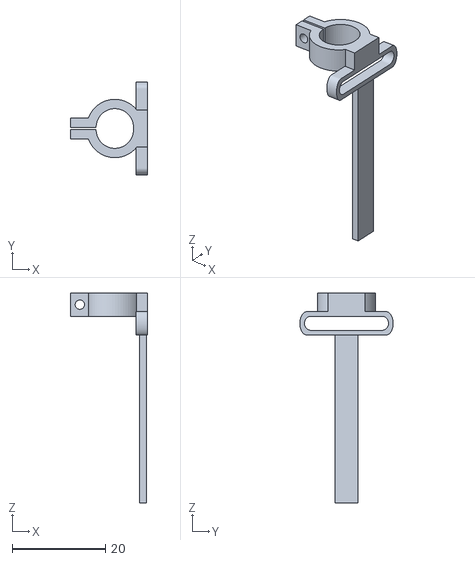
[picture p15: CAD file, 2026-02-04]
files/cad/drawbot_penlifter1.stl
16.5 x 20.0 x 45.0

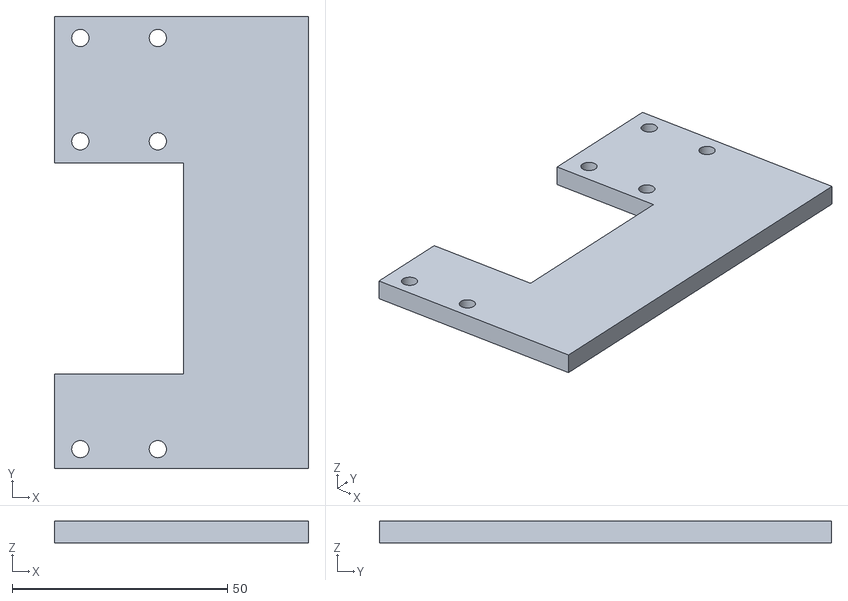
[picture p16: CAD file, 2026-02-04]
files/cad/drawbot_toolheadplate2.stl
59.0 x 105.0 x 5.00

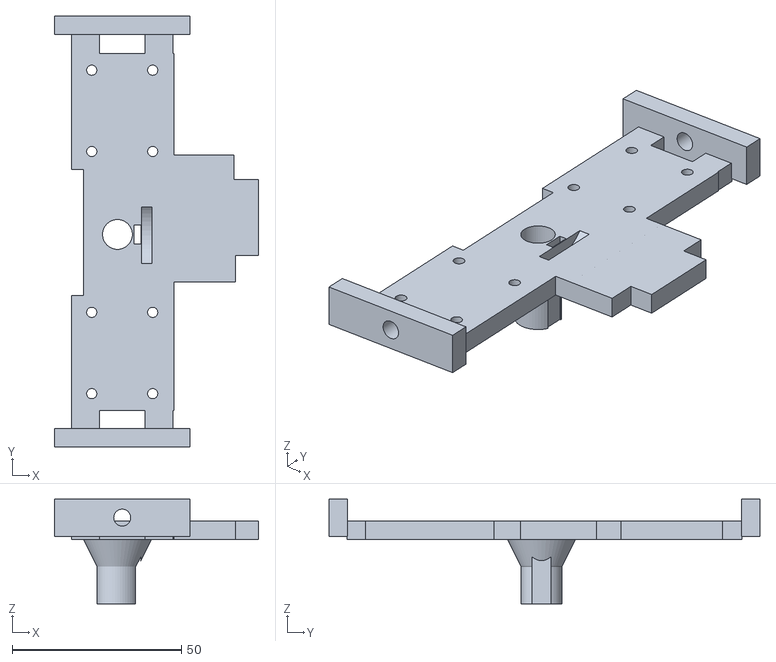
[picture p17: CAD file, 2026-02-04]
files/cad/drawbot_toolheadplate1.stl
60.2 x 127.2 x 31.0

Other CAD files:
files/cad/drawbot_gantryplate1.stl
files/cad/drawbot_idlermount1.stl
files/cad/drawbot_steppermount1.stl

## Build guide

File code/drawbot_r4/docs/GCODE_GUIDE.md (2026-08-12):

# Drawbot — G-code guide for contributors

The drawbot is a CoreXY pen plotter with a 400 mm × 300 mm drawing area
(paper anchored at the home corner). It speaks a deliberately small subset
of G-code: absolute millimetre moves only, with explicit pen control.

If your file follows the rules below it will print. The fastest way to be
sure is to run it through the validator:

```sh
python3 code/drawbot_r4/tools/gcode_check.py my_drawing.gcode
# → "OK: safe to draw on 400x300 mm paper"
```

## The complete command set

| Command | Meaning |
|---|---|
| `G21` | Millimetres (only unit; accepted, not required) |
| `G90` | Absolute positioning (only mode; accepted, not required) |
| `G0 X… Y… F…` | Raise the pen, then travel (max 2000 mm/min) |
| `G1 X… Y… F…` | Draw a straight line at the pen's current state (max 800 mm/min) |
| `M3` | Pen down |
| `M5` | Pen up |
| `M2` / `M30` | End of job: pen up, motors off |
| `M17` / `M18` | Motors on / off (operator use) |
| `M114` | Report position (operator use) |
| `M119` | Report switches (operator use) |
| `M50 X… Y…` | Mark current position (operator use — this is how homing is done) |
| `M280 S…` | Servo calibration pulse (operator use) |

Anything else is rejected: no arcs (`G2`/`G3`), no inches (`G20`), no
relative mode (`G91`), no multiple commands on one line.

## The rules (violations are rejected, not ignored)

- **One command per line.** No `G1 X10 Y10 M3`.
- **Coordinates are absolute millimetres** from the home corner, in
  `0 ≤ X ≤ 400`, `0 ≤ Y ≤ 300`. Anything outside is rejected — the machine
  never silently clamps. Leave a margin; the pen holder has physical width.
- **Line length ≤ 96 characters.**
- **Feed rates:** `G0` up to `2000`, `G1` up to `800` mm/min. `F` is
  optional — `G0` defaults to 2000, `G1` defaults to 800. Feed is **not**
  remembered from line to line.
- **Comments:** anything after `;` is ignored (also `( ... )`).
- **`G28` will not work** (a faulty limit switch) — the operator homes
  manually. Don't put `G28` in your file.
- **Don't try to print faster** by raising feeds or disabling limits — the
  machine rejects out-of-range values on purpose.

## The one thing everyone gets wrong: the pen

`G1` does **not** lower the pen — it only moves it. You must say `M3`
(pen down) yourself, and `M5` (pen up) when done:

```
M3        ; pen down
G1 X100 Y10 F800
G1 X100 Y100
M5        ; pen up
```

`G0` **always** raises the pen (that's what travel means). So a typical
drawing alternates: `G0` somewhere, `M3`, a few `G1` lines, `M5`, `G0`
somewhere else, and so on. Files that never issue `M3` draw nothing.

## Minimal working file

```gcode
; 60x40 mm rectangle with a diagonal
G21
G90
M5
G0 X20 Y20 F2000
M3
G1 X80 Y20 F800
G1 X80 Y60
G1 X20 Y60
G1 X20 Y20
M5
M2
```

## Generating files with a tool

- **SVG → G-code:** the standard pipeline is [vpype](https://vpype.readthedocs.io/)
  with the `vpype-gcode` plugin. Feed it the machine's numbers:
  units `mm`, `PEN_DOWN_COMMAND = M3`, `PEN_UP_COMMAND = M5`,
  `G1` feed ≤ 800, `G0` feed ≤ 2000, and clip the artwork to a 400×300 mm
  box placed at the origin. Then run the result through `gcode_check.py`.
- **Any other converter or slicer:** same checklist — only `G0/G1/M3/M5`,
  absolute mm, your feeds within the limits, your coordinates inside the
  box. Strip whatever else the tool emits (tool changes, arcs, G28,
  relative moves, M-codes the machine doesn't know). `gcode_check.py` will
  list exactly what to fix.
- **By hand:** the table above is the whole language; the minimal file is
  your template.

## Handing a file to the machine

1. Send the `.gcode` file to the operator (AirDrop is fine) — or just print
   this guide's rules and let them use `gcode_check.py` first.
2. The operator: paper in place, pen inked, carriage parked at the home
   corner, then:
   ```sh
   python3 code/drawbot_r4/tools/stream_gcode.py --ble your_file.gcode
   ```
3. The machine prints it end to end; a dropped Bluetooth link is recovered
   automatically mid-job.

## Quick reference: feed vs speed

| Move | Feed (mm/min) | mm/s |
|---|---|---|
| `G0` travel | 2000 | 33 |
| `G1` drawing | 800 | 13 |

A 100 mm line takes about 7.5 s. The whole 400×300 mm cross-hatch
presentation pattern takes about 30 minutes.

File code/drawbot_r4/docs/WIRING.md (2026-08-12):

# Wiring and power guide

Disconnect USB, 24 V, and the servo buck before changing any wire, driver, motor, or microstep jumper. Never plug or unplug a stepper while its driver is powered.

## Signal assignment

| Function | CNC Shield location | Uno R4 pin | Firmware name |
|---|---|---:|---|
| CoreXY motor A | X driver socket | STEP D2, DIR D5 | `PIN_MOTOR_A_*` |
| CoreXY motor B | Y driver socket | STEP D3, DIR D6 | `PIN_MOTOR_B_*` |
| Shared A4988 MS1 | Empty Z socket DIR | D7 | `PIN_MICROSTEP_MS1` |
| Shared driver enable | Shield enable net | D8, active-low | `PIN_DRIVER_ENABLE` |
| Left home switch | X− end-stop signal | D9 | `PIN_HOME_X` |
| Bottom home switch | Y− end-stop signal | D10 | `PIN_HOME_Y` |
| Removable probe button | Z− end-stop signal | D11 | `PIN_PROBE` |
| Servo signal only | Unused Z.STEP breakout | D4 | `PIN_SERVO` |
| Shared A4988 MS2 | SpnEn | D12 | `PIN_MICROSTEP_MS2` |
| Shared A4988 MS3 | SpnDir | D13 | `PIN_MICROSTEP_MS3` |

The home switches and probe are configured as `INPUT_PULLUP`: connect each normally-open contact between its signal pin and GND. It should read `open` normally and `TRIGGERED` when pressed. Use the shield labels or a continuity meter to identify signal and GND; do not guess the position of a three-pin header and do not connect a switch to 5 V.

## Power domains

```text
Mains ── enclosed/fused 24 V supply ── emergency cutoff ── CNC Shield VMOT
                                                   └───── 24→5 V buck ── servo +5 V
USB-C ─────────────────────────────────────────────────── Uno R4 logic power

Servo GND ───────── buck GND ───────── shield GND ─────── Uno R4 GND
Servo signal ───────────────────────────────────────────── D4 / Z.STEP
```

- Connect 24 V only to the shield motor-power terminal, with polarity checked before energising it.
- Power the R4 from USB-C for version 1.
- Power the servo only from the 5 V buck. The buck must have enough surge current for the servo; 2 A or more is a sensible starting point for a typical hobby servo.
- Join all grounds. Do **not** join the buck's +5 V output to the R4/shield 5 V rail.
- Put at least 100 µF, preferably a 50 V-rated electrolytic, across VMOT and GND near the drivers. Put 470–1000 µF across the servo's buck output near the servo. Observe capacitor polarity.
- Fuse the 24 V branch, cover mains terminals, provide an accessible motor-power cutoff, and connect protective earth to exposed metal/enclosures where the power supply's instructions require it.

The R4 accepts 6–24 V on VIN, but 24 V is the stated upper limit and the motor rail is electrically noisy. Its datasheet also calls for external servo power. Keeping USB logic power and the buck is the safer arrangement.

## A4988 setup

1. Remove the three microstep jumper headers under both X and Y sockets. With the shield unpowered and drivers removed, identify the control-side pad of each pair by continuity to the corresponding A4988 socket MS pin. The opposite pad is +5 V and must remain isolated.
2. Wire D7/Z-DIR directly to the X and Y MS1 control pads; D12/SpnEn to both MS2 pads; and D13/SpnDir to both MS3 pads. The A4988 provides internal pull-downs, so no external resistors are required. Verify that none of these three nets has continuity to +5 V before reinstalling drivers.
3. Identify each driver's `VMOT`, `GND`, `VDD`, `1A`, and `1B` labels and match those to the socket labels. Clone board colours and potentiometer positions are not reliable orientation guides.
4. Identify each motor's two coil pairs with a continuity meter. One coil goes to 1A/1B and the other to 2A/2B. A motor that only buzzes usually has interleaved coil wires.
5. Set current with the motor disconnected and motor power applied, using an insulated screwdriver and meter. For the common A4988 relation, `I_limit = VREF / (8 × R_sense)`. Thus 0.8 A is about 0.64 V with `R100` (0.10 Ω) resistors or 0.32 V with `R050` (0.05 Ω) resistors. Confirm the actual resistor marking and carrier documentation before relying on those examples.
6. Start near 0.8 A/phase. Do not exceed roughly 1 A without suitable heatsinks and airflow even though the motors are rated higher.

The mode truth table is full=`000`, half=`100`, quarter=`010`, eighth=`110`, and sixteenth=`111` for MS1/MS2/MS3. Firmware changes mode only at an electrical position common to both the old and new resolutions.

If an axis moves opposite the expected direction, change `MOTOR_A_DIRECTION_INVERTED` or `MOTOR_B_DIRECTION_INVERTED` in `config.h` after determining which motor is reversed. Always remove power before swapping motor wires.

## Servo connection

The servo's signal lead goes to D4/Z.STEP; its power and ground go to the buck. Do not plug all three servo leads into an arbitrary shield header. The R4 Servo library can drive D4, while the Z driver socket remains empty.

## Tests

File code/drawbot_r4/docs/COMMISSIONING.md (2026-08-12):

# Commissioning and verification

Work through this in order. Automated homing is intentionally late in the process.

## 1. Unpowered inspection

- Confirm the shield is seated without offset pins or bent headers.
- Verify A4988 orientation from pin labels, but leave both modules out initially.
- Verify all six microstep jumper headers are removed. Check continuity from D7 to both MS1 control pads, D12 to both MS2 pads, and D13 to both MS3 pads. Confirm all three nets are isolated from +5 V.
- Check 24 V polarity, fusing, emergency cutoff, capacitor polarity, common ground, and that buck +5 V is isolated from Arduino +5 V.
- Confirm each motor's two coil pairs with a continuity meter.
- Confirm each switch is normally open: infinite/open normally, near zero ohms when pressed.

## 2. Inputs, no drivers or motor power

Upload the firmware and connect USB only. At 115200 baud it should print `ready`. Run `M119` repeatedly while pressing one input at a time:

```text
M119
x_home:open y_home:open probe:open
ok
```

Each input must change only its own field to `TRIGGERED`. Correct wiring or `*_ACTIVE_LEVEL` before continuing.

## 3. Calibrate the servo safely

The R4 Servo library initially attaches at a standard 1500 µs pulse before accepting the first `M280`. Because the old mechanism's safe range is unknown, perform the first attach with the servo buck **off** (or with the horn/yoke mechanically disconnected):

1. Send `M280 S1000` while the servo has no power. The firmware now holds a 1000 µs signal.
2. Apply servo-buck power with a hand on its cutoff. If the mechanism strains, remove power immediately.
3. Move in small increments such as `M280 S1020`, never jumping blindly across the range. Find a pulse that clears the board everywhere and a center pulse that gives light, reliable contact.
4. Find conservative mechanical minimum and maximum pulse bounds that cannot jam the yoke.
5. Put those values into `PEN_UP_US`, `PEN_DOWN_CENTER_US`, `SERVO_SAFE_MIN_US`, and `SERVO_SAFE_MAX_US` in `config.h`. Set `PEN_CALIBRATED = true`, rebuild, and retest `M5`/`M3` at the center.
6. If the recovered surface correction acts in the wrong direction, change `HEIGHTMAP_SIGN` from `1` to `-1`. Adjust pressure only with `PEN_PRESSURE_OFFSET_US`.

The recovered 915–1045 µs measurements are never used as absolute commands. The firmware subtracts the recovered center value (945 µs) and adds only that relative offset to the newly calibrated center-down pulse.

## 4. Driver and motor bench test

Set and verify each VREF before connecting a motor. With belts disengaged so one motor cannot rack the gantry, use `tools/driver_bench_test/driver_bench_test.ino` to test one socket, driver, and motor at a time. Power everything off before installing/removing a driver or motor. The motor should rotate smoothly in both directions without buzzing, excessive heat, or shutdown.

Restore the main firmware after both channels pass. Reconnect the mechanics and turn both motors by hand with power removed; the gantry should move smoothly without binding.

## 5. Direction checks before homing

Keep a hand on the 24 V cutoff. Confirm both switches still report correctly with `M119`. For the first `G28`, begin with the carriage near the middle and be ready to cut motor power.

The machine must first move left, back off, touch left slowly, release, then repeat downward. If it moves away from a switch, cut 24 V immediately and correct the appropriate direction-inversion constant. If a switch is hit but motion continues, stop and fix the input before trying again.

After a successful home, `M114` should report approximately `X:0.000 Y:0.000 homed:yes microstep:1/16` and both switches should be open because the firmware finishes with clearance from the contacts.

## 6. Mechanical calibration

1. Run ten homing cycles and mark/measure the returned pen position. Investigate any visible spread or missed latch.
2. With the pen raised, command 100 mm X and Y moves and measure actual travel. Update `BASE_UNITS_PER_MM` using `new = old × commanded / measured`.
3. Draw `examples/calibration_square.gcode`, then diagonal lines and a host-generated segmented circle. Check size, squareness, belt tension, and skipped steps.
4. Tune current and acceleration conservatively. Do not increase current to hide mechanical binding.

## 7. Endurance run

Run a representative drawing continuously for 30 minutes. Stop if a driver enters thermal shutdown, the R4 resets, the servo supply sags, wiring or connectors heat up, or the machine skips steps. Only declare the machine commissioned after it completes without any of those symptoms.

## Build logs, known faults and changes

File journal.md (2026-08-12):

---
title: "drawbot"
author: "Ewoud Van Vooren"
description: "A drawing machine that is as fast and as cheap as possible"
created_at: "2025-05-25"
---

## Journal

### Total time spent: 25hrs and 35 mins

**18/5/25** *time spent: 1 hr*
 - repo created, organized it
 - made pr to highway repo
 - made bom
    - found all the parts
        - Arduino Uno REV3
        - 12V 2A Power Supply
        - 2020 V Slot Aluminum Extrusion
        - Linear Motion Rod
        - Linear Ball Bearings
        - Stepper Motor Nema 17
        - 5M GT2 Timing Belt 6mm Width
        - Stepper Motor Driver Module

**19/5/25** *time spent: 30 mins*
 - updated journal [[commit](https://github.com/EwoudVV/drawbot/commit/50e35cfa68b8b6b28bf3ccec420033e38243821c)] from yesterday
 - update bom [[commit 1](https://github.com/EwoudVV/drawbot/commit/d7c03af33f3740dc8db9d91a1a45316af86a2cfb)][[commit 2](https://github.com/EwoudVV/drawbot/commit/1cbc16131d8af86ff61878edf334b16d864162b7)]
    - more misc items like screws, servo, bearings etc that i will need, found good links for those
    - made some small changes
 - made a nice readme, can update more [[commit](https://github.com/EwoudVV/drawbot/commit/9d6c27ab3a7f5787f335faa75507cd3d0add2d44)]

**21/5/25** *time spent: 15 mins*
 - found some nice limit switches for homing on digikey, updated bom

**23/5/25** *time spent: 20 mins*
 - found stl files for some parts
 - started designing
 - 

**24/5/25** *time spent: 1 hr*
 - researched how to do stuff with aluminum extrusions
 - looked at my printer for inspiration on how to connect those
 - most of the connectors i found required tapping, which i dont have tools for
 - updated bom with good parts i found [[commit](https://github.com/EwoudVV/drawbot/commit/4ae2a4a4eb12693b451b2eabf4d3502016529dd1)]
     - parts include connection parts to connect the extrusions securely
         - they slide in to the v part, and then i tighten them with grub screws so that no tapping threads is required
     - also wheel rollers, 2 bases for them (4 rollers each) and adjusting nuts for the wheel. the rollers roll on the aluminum extrusions, a base on each side. The linear bearings are connected to those for the other axis.
 - update: i found much cheaper parts, specifically for the roller. amazon had a pack of 2 of the whole thing (rollers, adjusters and plate included) for much cheaper than what i first found
 - i also found cheaper aluminum extrusions, that even came with connecter things and screws, so more stuff for less price
 - also got rid of the 12v 2a power supply, it wasnt neccessary bc i have a variable power supply that i can use

**14/6/25** *time spent: 1hr*
 - designed more:
 - 
 - i designed a rough thing of what the roller plates would look like on the extrusions with the right dimensions, and put the linear motion rods in the right place
 - i looked at the reviews for some of the parts listings, and i found that the roller plate had bad reviews (almost everyone said it was assembled wrong, bad quality) so i found a better brand that had much better reviews and that was even cheaper.

**27/6/25** *time spent: 30 mins*
 - made a better replica of the sliding gantry plate on the aluminum extrusions so i can better model a mount for the linear bearings: 

**29/6/25** *time spent: 1 hr*
 - i designed a plate for in between the aluminum gantry plate and the linear bearing holders (which i found the stl for), and it has screw holes with countersunk things for the screws. I also aligned everything perfectly.

**1/7/25** *time spent: 3 hrs*
 - i made the part for the pen lifting system
 - 
 - first i made the base, which screws on to the bottom of the linear bearings. i made a hole for the pen with a bit bigger diameter for the pen (which i chose to be a Bic Round Stic because it is simple and cylindrical) and i put an extrusion on the bottom of the plate for the pen so it would wobble less.
 - i put a mounting place for the servo
 - for moving the pen up and down, i used a mechanism called a [scotch yoke](https://www.youtube.com/watch?v=4iP_ZPBduSo). it converts rotational movement from the servo into linear movement for the pen.
 - i made the clamp for the screw, which has tabs on the end of the piece that wraps around the pen and is attached to part of the scotch yoke mechanism, and to tighten it, i will put a bolt and nut into the tabs and tighten it around the pen so that it stays in place well.
 - i also tried to remove unnessecary sections of the plate, because i want the draw bot to move fast and have high acceleration, so it needs less mass on the moving parts.
 - 
 - 

**23/7/25** *time spent: 15 hrs*
 - kind of a while since my last journal entry but I finished it!
 - I finished the belt system
    - I put idler and drive wheels in the places that they needed to go
    - 
    - I made spots to clamp the belt and the toolhead. The timing belt comes with the clamps.
    - 
    - I made attatchments at the opposite corners of the motors where idler wheels will go. They attatch to the aluminum extrusions
    - 
    - I reasearched the CoreXY/cartesian belt design and layed out where the belts would go on the drawing machine, and color coded both of them. I also calculated the lengths of the belts to total to about 4.5 meters, which is good because the belt i will buy is 5 meters.
    - 
    - I made attatchements on the other 2 corners for the stepper motor base. I copied the attatchment design for the other side and used it, and made a base.
    - 

**25/7/25** *time spent: 1 hr*
 - (Im combining stuff I did recently)
 - Im doing final checks from the website before submitting
 - I uploaded some images of the design in the new folder
 - I designed the wiring diagram for the stepper motor drivers and the arduino (which i already have, so i dont need to add it to the bom)
 - schematic

**25/7/25** *time spent: 1hr*
 - I coded some code for the drawing machine. It homes it, then goes to coordinates specified in the serial monitor. [[commit](https://github.com/EwoudVV/drawbot/commit/557fd0dd407ad2a281d6dc4d6faa46b979bcdcc2)]

**1/8/26** *time spent: long session*
 - Debugged the "never reverses" bug: the Uno R4 core resets the output data register on `pinMode(OUTPUT)`, so every `digitalWrite`-then-`pinMode` write collapsed to LOW. All writes must be `pinMode` first, then `digitalWrite`.
 - The CNC Shield V3.00 ENABLE net (D8) is direct and active-LOW (R1 pull-up, no inverter) — the old "inverted" assumption was wrong; fixed `DRIVER_ENABLE_ACTIVE_LEVEL = LOW`. There is no D13-to-RESET "R10" rail; MS pins only set stepping resolution.
 - Corrected the CoreXY Y-sign convention for this machine's belt routing (A advances X-Y, B advances X+Y).
 - **Commissioned the machine**: pen calibrated (500 us down / 1500 us up), scale verified (80.8 units/mm), manual homing via `M50`, 100 mm square drawn, and a **35-minute endurance run** (full-workspace cross-hatch) completed with zero BLE drops or errors.
 - The bottom (Y-) limit switch never triggers on any header despite perfect continuity — decided to operate with manual homing.
 - `stream_gcode.py` hardened: BLE drop recovery with M114 position reconciliation, 20-byte chunked writes with pacing, auto-M50 at start. `gen_stress_pattern.py` generates the cross-hatch presentation pattern.
 - The Uno R4 now lives on the 0.5m square machine with the CNC shield; the original Uno R3 sketch is still in `code/`.

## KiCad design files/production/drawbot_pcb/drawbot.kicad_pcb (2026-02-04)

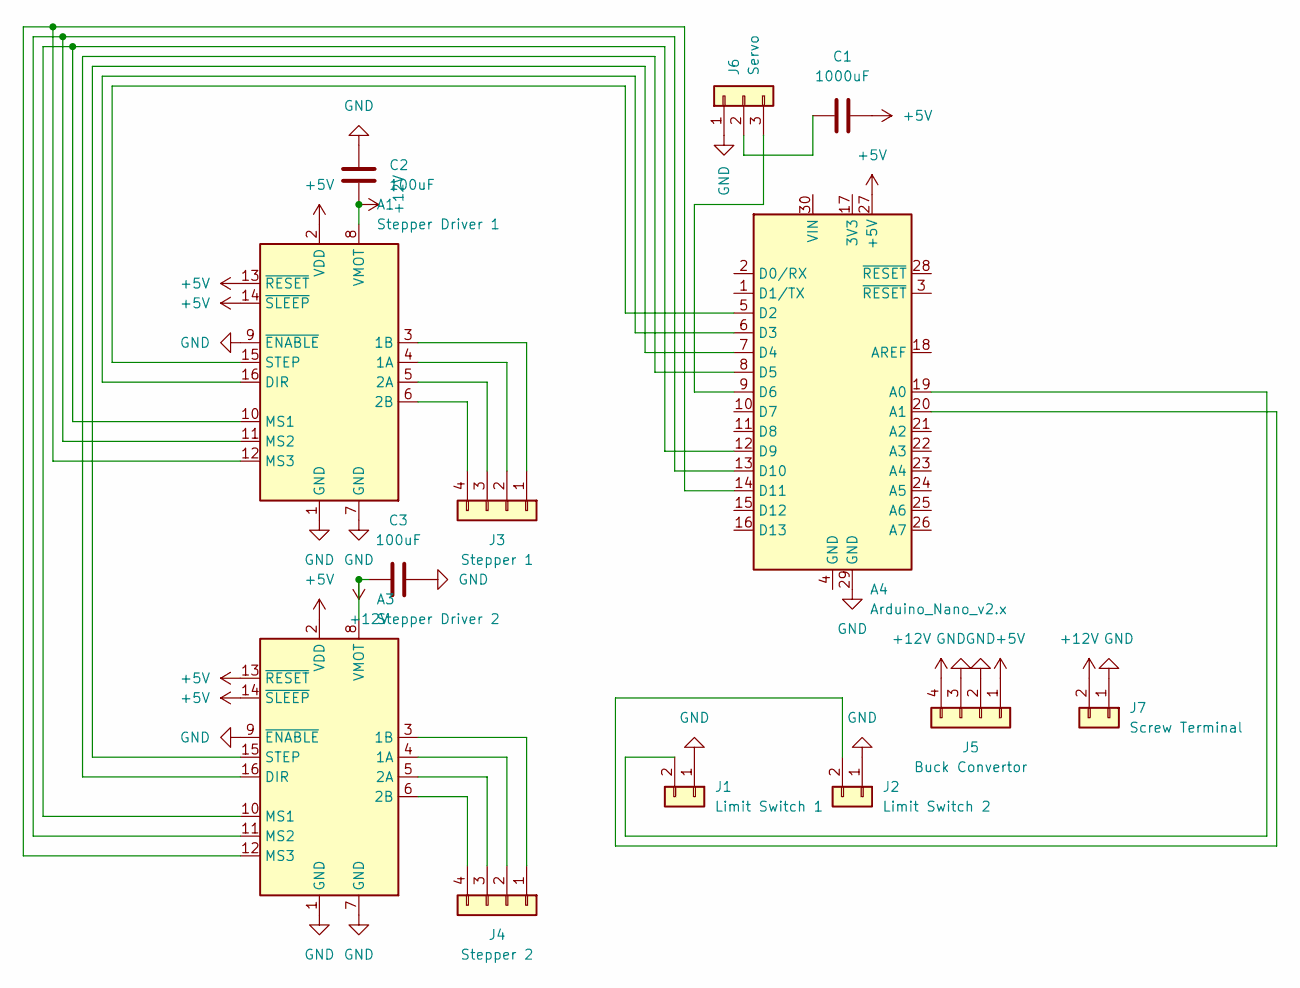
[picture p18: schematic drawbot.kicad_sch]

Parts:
A1: Stepper Driver 1; Pololu_Breakout-16_15.2x20.3mm
A3: Stepper Driver 2; Pololu_Breakout-16_15.2x20.3mm
A4: Arduino_Nano_v2.x; Arduino_Nano
C1: 1000uF; CP_Radial_D10.0mm_P5.00mm
C2, C3: 100uF; CP_Radial_D6.3mm_P2.50mm
J1: Limit Switch 1; PinHeader_1x02_P2.54mm_Vertical
J2: Limit Switch 2; PinHeader_1x02_P2.54mm_Vertical
J3: Stepper 1; PinHeader_1x04_P2.54mm_Vertical
J4: Stepper 2; PinHeader_1x04_P2.54mm_Vertical
J5: Buck Convertor; PinHeader_1x04_P2.54mm_Vertical
J6: Servo; PinHeader_1x03_P2.54mm_Vertical
J7: Screw Terminal; TerminalBlock_bornier-2_P5.08mm

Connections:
+5V: A1.2 (VDD), A1.13 (~RESET), A1.14 (~SLEEP), A3.2 (VDD), A3.13 (~RESET), A3.14 (~SLEEP), A4.27 (+5V), C1.1, J5.1
+12V: A1.8 (VMOT), A3.8 (VMOT), C2.2, C3.1, J5.4, J7.2
GND: A1.1 (GND), A1.7 (GND), A1.9 (~ENABLE), A3.1 (GND), A3.7 (GND), A3.9 (~ENABLE), A4.29 (GND), C2.1, C3.2, J1.1, J2.1, J5.2, J5.3, J6.1, J7.1
unnamed: A1.4 (1A), J3.2
unnamed: A1.3 (1B), J3.1
unnamed: A1.5 (2A), J3.3
unnamed: A1.6 (2B), J3.4
unnamed: A1.16 (DIR), A4.6 (D3)
unnamed: A1.10 (MS1), A3.10 (MS1), A4.12 (D9)
unnamed: A1.11 (MS2), A3.11 (MS2), A4.13 (D10)
unnamed: A1.12 (MS3), A3.12 (MS3), A4.14 (D11)
unnamed: A1.15 (STEP), A4.5 (D2)
unnamed: A3.4 (1A), J4.2
unnamed: A3.3 (1B), J4.1
unnamed: A3.5 (2A), J4.3
unnamed: A3.6 (2B), J4.4
unnamed: A3.16 (DIR), A4.8 (D5)
unnamed: A3.15 (STEP), A4.7 (D4)
unnamed: A4.19 (A0), J1.2
unnamed: A4.20 (A1), J2.2
unnamed: A4.9 (D6), J6.3
unnamed: C1.2, J6.2

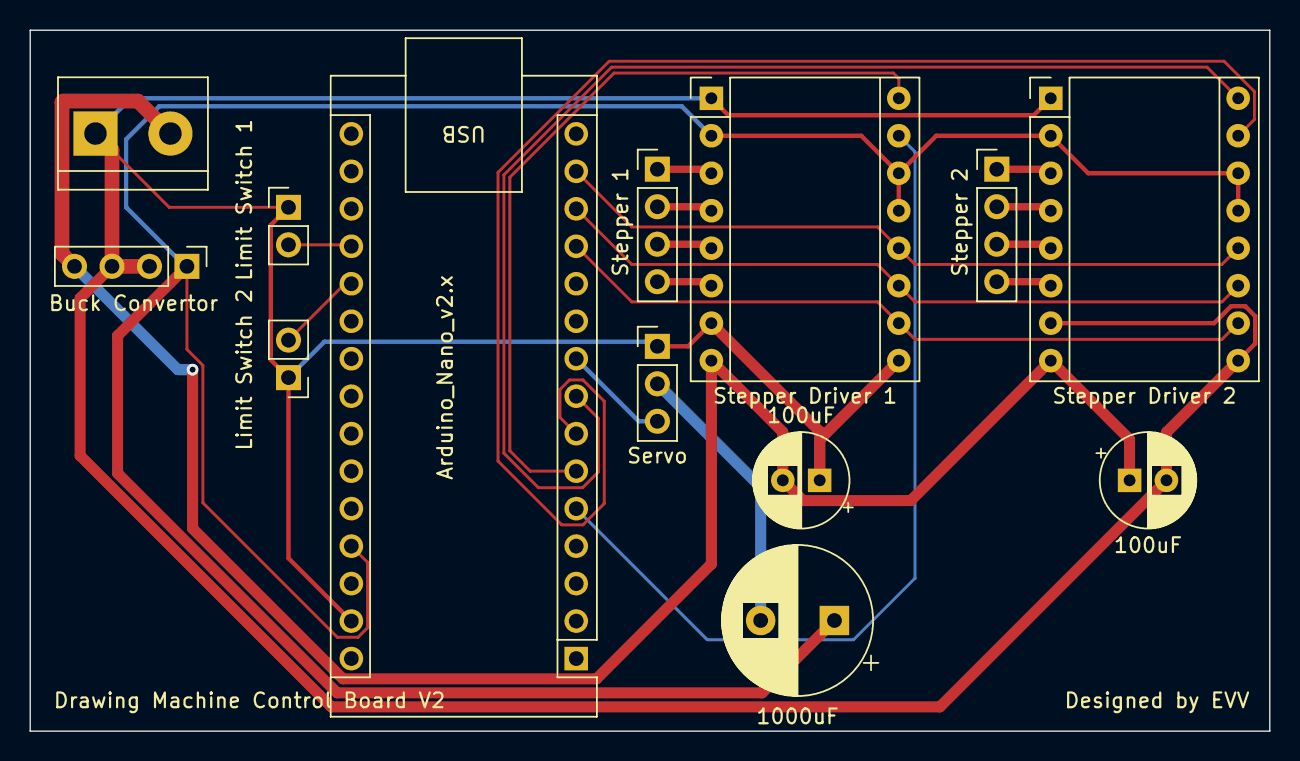
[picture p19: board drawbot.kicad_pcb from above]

Board: 2 copper layers, 84.0 x 47.5 mm, 13 parts (0 on the bottom side), 22 nets.

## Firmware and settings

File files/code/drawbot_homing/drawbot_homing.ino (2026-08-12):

/*
  ESP32 CoreXY pen plotter: minimal G-code interpreter (absolute, mm)
  Updated:
    - On M2/M30: pen up, HOME (left then down), reset modal state, keep accepting more jobs.
    - Still stops permanently on "error:" until reset.

  Supported:
    G21                ; set mm units (required before motion)
    G90                ; absolute mode (required before motion)
    G0 X.. Y.. [F..]   ; travel (forces pen up)
    G1 X.. Y.. [F..]   ; draw   (forces pen down)
    M3                 ; pen down
    M5                 ; pen up
    M2 / M30           ; end job (pen up, home, ready)

    - F is interpreted as mm/min.
    - Coordinates are clamped to the workspace.
    - Executes line-by-line over Serial and replies "ok" per line.
    - Homes on boot: left until X switch, then down until Y switch.

  Pins:
    MS1=18 MS2=19 MS3=21
    Left motor:  STEP_L=32 DIR_L=33
    Right motor: STEP_R=26 DIR_R=25
    Limit X-left: GPIO34 (pressed -> GND, needs external pullup to 3.3V)
    Limit Y-down: GPIO35 (pressed -> GND, needs external pullup to 3.3V)
    Servo: GPIO27 (powered from 5 V buck, common GND)

  Limit switch pullups:
    GPIO34/35 do NOT have internal pullups.
    Add 10k from GPIO34 -> 3.3V and 10k from GPIO35 -> 3.3V.
    Switch between GPIO pin and GND. Pressed reads LOW.
*/

#include <Arduino.h>
#include <ESP32Servo.h>
#include <math.h>

// ---------------- Pins ----------------
constexpr int MS1_PIN = 18;
constexpr int MS2_PIN = 19;
constexpr int MS3_PIN = 21;

constexpr int STEP_L = 32;
constexpr int DIR_L = 33;

constexpr int STEP_R = 26;
constexpr int DIR_R = 25;

constexpr int LIMIT_X_LEFT = 34;
constexpr int LIMIT_Y_DOWN = 35;

constexpr int SERVO_PIN = 27;

// ---------------- Workspace ----------------
constexpr float X_MAX_MM = 400.0f;
constexpr float Y_MAX_MM = 320.0f;

// Calibration base (axis-step units per mm at full step)
constexpr float BASE_STEPS_PER_MM_FULLSTEP = 10.0f;

// Fixed microstepping for v1
constexpr int MICROSTEP_FACTOR = 8;

// ---------------- Motor capability model ----------------
constexpr float MOTOR_MAX_RPM = 200.0f;
constexpr float MOTOR_FULL_STEPS_PER_REV = 200.0f;
constexpr float MOTOR_MAX_FULLSTEP_SPS =
    (MOTOR_MAX_RPM * MOTOR_FULL_STEPS_PER_REV) / 60.0f;  // ~666.7 full-steps/s
constexpr float MOTOR_MAX_MICROSTEP_SPS =
    MOTOR_MAX_FULLSTEP_SPS * MICROSTEP_FACTOR;

// ---------------- Timing ----------------
constexpr uint16_t PULSE_US = 8;

// Default feedrates (mm/min)
constexpr float FEED_TRAVEL_MM_MIN = 3000.0f;
constexpr float FEED_DRAW_MM_MIN = 1200.0f;
constexpr float FEED_HOME_MM_MIN = 600.0f;

constexpr uint32_t MAX_HOME_STEPS = 400000;

// ---------------- Servo ----------------
constexpr int SERVO_HZ = 50;
constexpr int SERVO_MIN_US = 500;
constexpr int SERVO_MAX_US = 2500;

// Your calibration
constexpr int PEN_UP_US = 1000;
constexpr int PEN_DOWN_US = 2000;

// ---------------- State ----------------
Servo penServo;

bool units_mm = false;
bool absolute_mode = false;
bool stopped = false;

float cur_x_mm = 0.0f;
float cur_y_mm = 0.0f;

float current_feed_mm_min = FEED_TRAVEL_MM_MIN;
uint32_t step_low_delay_us = 2000;

// ---------------- Parsing ----------------
struct ParsedLine {
  bool hasG = false;
  int g = -1;

  bool hasM = false;
  int m = -1;

  bool hasX = false;
  float x = 0.0f;

  bool hasY = false;
  float y = 0.0f;

  bool hasF = false;
  float f = 0.0f;
};

// ---------------- Helpers ----------------
static inline float clampf(float v, float lo, float hi) {
  if (v < lo) return lo;
  if (v > hi) return hi;
  return v;
}

static inline int32_t iround(float x) {
  return (int32_t)lroundf(x);
}

static inline bool swPressed(int pin) {
  return digitalRead(pin) == LOW;
}

static inline void setMotorDirs(bool dirL_forward, bool dirR_forward) {
  // L+: up-right, R+: down-right
  digitalWrite(DIR_L, dirL_forward ? HIGH : LOW);
  digitalWrite(DIR_R, dirR_forward ? HIGH : LOW);
}

static inline void pulseOne(int stepPin) {
  digitalWrite(stepPin, HIGH);
  delayMicroseconds(PULSE_US);
  digitalWrite(stepPin, LOW);
  delayMicroseconds(step_low_delay_us);
}

static inline void pulseBoth() {
  digitalWrite(STEP_L, HIGH);
  digitalWrite(STEP_R, HIGH);
  delayMicroseconds(PULSE_US);
  digitalWrite(STEP_L, LOW);
  digitalWrite(STEP_R, LOW);
  delayMicroseconds(step_low_delay_us);
}

static inline float stepsPerMmEffective() {
  return BASE_STEPS_PER_MM_FULLSTEP * (float)MICROSTEP_FACTOR;
}

void setMicrosteppingFixed() {
  // A4988:
  // 1    : L L L
  // 1/2  : H L L
  // 1/4  : L H L
  // 1/8  : H H L
  // 1/16 : H H H
  bool ms1 = LOW, ms2 = LOW, ms3 = LOW;

  if (MICROSTEP_FACTOR == 1) { ms1 = LOW; ms2 = LOW; ms3 = LOW; }
  else if (MICROSTEP_FACTOR == 2) { ms1 = HIGH; ms2 = LOW; ms3 = LOW; }
  else if (MICROSTEP_FACTOR == 4) { ms1 = LOW; ms2 = HIGH; ms3 = LOW; }
  else if (MICROSTEP_FACTOR == 8) { ms1 = HIGH; ms2 = HIGH; ms3 = LOW; }
  else if (MICROSTEP_FACTOR == 16) { ms1 = HIGH; ms2 = HIGH; ms3 = HIGH; }

  digitalWrite(MS1_PIN, ms1);
  digitalWrite(MS2_PIN, ms2);
  digitalWrite(MS3_PIN, ms3);
}

void setFeedMmMin(float f_mm_min) {
  if (f_mm_min <= 0.0f) return;

  current_feed_mm_min = f_mm_min;

  float v_mm_s = f_mm_min / 60.0f;
  float axis_sps = v_mm_s * stepsPerMmEffective();

  // Conservative clamp to motor capability
  float axis_sps_cap = 2.0f * MOTOR_MAX_MICROSTEP_SPS;
  if (axis_sps > axis_sps_cap) axis_sps = axis_sps_cap;

  float period_us = 1000000.0f / axis_sps;
  float low_us = period_us - (float)PULSE_US;
  if (low_us < 50.0f) low_us = 50.0f;

  step_low_delay_us = (uint32_t)lroundf(low_us);
}

void penUp() {
  penServo.writeMicroseconds(PEN_UP_US);
  delay(200);
}

void penDown() {
  penServo.writeMicroseconds(PEN_DOWN_US);
  delay(200);
}

// ---------------- CoreXY diagonal move ----------------
// L+ => (+x,+y), R+ => (+x,-y)
//
// dx_steps = sL + sR
// dy_steps = sL - sR
// => sL = (dx+dy)/2, sR = (dx-dy)/2
void moveByAxisSteps(int32_t dxSteps, int32_t dySteps) {
  float sLf = 0.5f * (dxSteps + dySteps);
  float sRf = 0.5f * (dxSteps - dySteps);

  int32_t sL = iround(sLf);
  int32_t sR = iround(sRf);

  bool dirL = (sL >= 0);
  bool dirR = (sR >= 0);

  uint32_t nL = (uint32_t)labs(sL);
  uint32_t nR = (uint32_t)labs(sR);

  setMotorDirs(dirL, dirR);

  if (nL == 0 && nR == 0) return;

  uint32_t nMax = (nL > nR) ? nL : nR;
  int32_t errL = 0;
  int32_t errR = 0;

  for (uint32_t i = 0; i < nMax; i++) {
    bool stepL = false;
    bool stepR = false;

    errL += (int32_t)nL;
    errR += (int32_t)nR;

    if (errL >= (int32_t)nMax) { errL -= (int32_t)nMax; stepL = true; }
    if (errR >= (int32_t)nMax) { errR -= (int32_t)nMax; stepR = true; }

    if (stepL && stepR) pulseBoth();
    else if (stepL) pulseOne(STEP_L);
    else if (stepR) pulseOne(STEP_R);
    else delayMicroseconds(step_low_delay_us);
  }

  int32_t dxAch = sL + sR;
  int32_t dyAch = sL - sR;

  float spmm = stepsPerMmEffective();
  cur_x_mm += (float)dxAch / spmm;
  cur_y_mm += (float)dyAch / spmm;

  cur_x_mm = clampf(cur_x_mm, 0.0f, X_MAX_MM);
  cur_y_mm = clampf(cur_y_mm, 0.0f, Y_MAX_MM);
}

void moveToMm(float xMm, float yMm) {
  float tx = clampf(xMm, 0.0f, X_MAX_MM);
  float ty = clampf(yMm, 0.0f, Y_MAX_MM);

  float dxMm = tx - cur_x_mm;
  float dyMm = ty - cur_y_mm;

  float spmm = stepsPerMmEffective();
  int32_t dxSteps = iround(dxMm * spmm);
  int32_t dySteps = iround(dyMm * spmm);

  moveByAxisSteps(dxSteps, dySteps);
}

// ---------------- Homing ----------------
// Left: DIR_L=LOW, DIR_R=LOW, step both until X switch pressed
// Down: DIR_L=LOW, DIR_R=HIGH, step both until Y switch pressed
bool homeLeft() {
  setFeedMmMin(FEED_HOME_MM_MIN);
  setMotorDirs(false, false);

  for (uint32_t i = 0; i < MAX_HOME_STEPS; i++) {
    if (swPressed(LIMIT_X_LEFT)) return true;
    pulseBoth();
  }
  return false;
}

bool homeDown() {
  setFeedMmMin(FEED_HOME_MM_MIN);
  setMotorDirs(false, true);

  for (uint32_t i = 0; i < MAX_HOME_STEPS; i++) {
    if (swPressed(LIMIT_Y_DOWN)) return true;
    pulseBoth();
  }
  return false;
}

bool doHome() {
  penUp();

  if (!homeLeft()) return false;
  if (!homeDown()) return false;

  cur_x_mm = 0.0f;
  cur_y_mm = 0.0f;

  setFeedMmMin(FEED_TRAVEL_MM_MIN);
  return true;
}

// ---------------- G-code parsing ----------------
String stripComments(const String &in) {
  int semi = in.indexOf(';');
  String s = (semi >= 0) ? in.substring(0, semi) : in;

  String out;
  out.reserve(s.length());
  bool inParens = false;
  for (size_t i = 0; i < s.length(); i++) {
    char c = s[i];
    if (c == '(') { inParens = true; continue; }
    if (c == ')') { inParens = false; continue; }
    if (!inParens) out += c;
  }
  out.trim();
  return out;
}

bool parseNumber(const String &s, int startIdx, float &value, int &endIdx) {
  int i = startIdx;
  while (i < (int)s.length() && s[i] == ' ') i++;

  int j = i;
  bool seenDigit = false;
  bool seenDot = false;

  if (j < (int)s.length() && (s[j] == '+' || s[j] == '-')) j++;

  for (; j < (int)s.length(); j++) {
    char c = s[j];
    if (c >= '0' && c <= '9') { seenDigit = true; continue; }
    if (c == '.' && !seenDot) { seenDot = true; continue; }
    break;
  }

  if (!seenDigit) return false;

  value = s.substring(i, j).toFloat();
  endIdx = j;
  return true;
}

bool parseLine(const String &lineIn, ParsedLine &pl) {
  String s = stripComments(lineIn);
  if (s.length() == 0) return true;

  s.toUpperCase();

  int i = 0;
  while (i < (int)s.length()) {
    char c = s[i];

    if (c == ' ' || c == '\t') { i++; continue; }

    if (c == 'G' || c == 'M' || c == 'X' || c == 'Y' || c == 'F') {
      float v = 0.0f;
      int endIdx = i + 1;
      if (!parseNumber(s, i + 1, v, endIdx)) return false;

      if (c == 'G') { pl.hasG = true; pl.g = (int)lroundf(v); }
      else if (c == 'M') { pl.hasM = true; pl.m = (int)lroundf(v); }
      else if (c == 'X') { pl.hasX = true; pl.x = v; }
      else if (c == 'Y') { pl.hasY = true; pl.y = v; }
      else if (c == 'F') { pl.hasF = true; pl.f = v; }

      i = endIdx;
      continue;
    }

    i++;
  }

  return true;
}

void hardStop(const char *msg) {
  penUp();
  stopped = true;
  Serial.print("error: ");
  Serial.println(msg);
}

// Reset modal state between jobs (after M2/M30)
void resetJobState() {
  units_mm = false;
  absolute_mode = false;
  setFeedMmMin(FEED_TRAVEL_MM_MIN);
  penUp();
}

// ---------------- Execute one parsed line ----------------
void executeParsed(const ParsedLine &pl) {
  // Unsupported meaning-changing modes
  if (pl.hasG && pl.g == 20) { hardStop("G20 inches unsupported"); return; }
  if (pl.hasG && pl.g == 91) { hardStop("G91 relative unsupported"); return; }

  // End job: home and keep going
  if (pl.hasM && (pl.m == 2 || pl.m == 30)) {
    penUp();
    if (!doHome()) {
      hardStop("homing failed after M2/M30");
      return;
    }
    resetJobState();
    Serial.println("ok");
    Serial.println("ready");
    return;
  }

  // Modal setup
  if (pl.hasG && pl.g == 21) units_mm = true;
  if (pl.hasG && pl.g == 90) absolute_mode = true;

  // Tool
  if (pl.hasM && pl.m == 3) penDown();
  if (pl.hasM && pl.m == 5) penUp();

  // Feedrate
  if (pl.hasF) setFeedMmMin(pl.f);

  // Motion
  bool isG0 = (pl.hasG && pl.g == 0);
  bool isG1 = (pl.hasG && pl.g == 1);

  if (isG0 || isG1) {
    if (!units_mm) { hardStop("missing G21"); return; }
    if (!absolute_mode) { hardStop("missing G90"); return; }

    if (isG0) {
      penUp();
      if (!pl.hasF && current_feed_mm_min <= 0.0f) setFeedMmMin(FEED_TRAVEL_MM_MIN);
    } else {
      penDown();
      if (!pl.hasF && current_feed_mm_min <= 0.0f) setFeedMmMin(FEED_DRAW_MM_MIN);
    }

    float tx = cur_x_mm;
    float ty = cur_y_mm;
    if (pl.hasX) tx = pl.x;
    if (pl.hasY) ty = pl.y;

    tx = clampf(tx, 0.0f, X_MAX_MM);
    ty = clampf(ty, 0.0f, Y_MAX_MM);

    moveToMm(tx, ty);
  }

  Serial.println("ok");
}

// ---------------- Arduino ----------------
void setup() {
  Serial.begin(115200);

  pinMode(MS1_PIN, OUTPUT);
  pinMode(MS2_PIN, OUTPUT);
  pinMode(MS3_PIN, OUTPUT);

  pinMode(STEP_L, OUTPUT);
  pinMode(DIR_L, OUTPUT);
  pinMode(STEP_R, OUTPUT);
  pinMode(DIR_R, OUTPUT);

  pinMode(LIMIT_X_LEFT, INPUT);
  pinMode(LIMIT_Y_DOWN, INPUT);

  setMicrosteppingFixed();

  penServo.setPeriodHertz(SERVO_HZ);
  penServo.attach(SERVO_PIN, SERVO_MIN_US, SERVO_MAX_US);

  setFeedMmMin(FEED_TRAVEL_MM_MIN);
  penUp();

  if (!doHome()) {
    hardStop("homing failed on boot");
    return;
  }

  resetJobState();

  Serial.println("ok");
  Serial.println("ready");
}

void loop() {
  if (stopped) {
    while (Serial.available()) Serial.read();
    delay(50);
    return;
  }

  if (!Serial.available()) return;

  String line = Serial.readStringUntil('\n');
  line.trim();

  ParsedLine pl;
  if (!parseLine(line, pl)) {
    hardStop("parse error");
    return;
  }

  executeParsed(pl);
}

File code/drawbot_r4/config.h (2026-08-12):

#pragma once

#include <Arduino.h>

namespace drawbot::config {

// CNC Shield V3.00 / GRBL 0.8 pin layout.
constexpr uint8_t PIN_MOTOR_A_STEP = 2;  // X socket STEP
constexpr uint8_t PIN_MOTOR_B_STEP = 3;  // Y socket STEP
constexpr uint8_t PIN_SERVO = 4;         // Unused Z.STEP breakout
constexpr uint8_t PIN_MOTOR_A_DIR = 5;   // X socket DIR
constexpr uint8_t PIN_MOTOR_B_DIR = 6;   // Y socket DIR
constexpr uint8_t PIN_MICROSTEP_MS1 = 7;   // Empty Z socket DIR
constexpr uint8_t PIN_DRIVER_ENABLE = 8;
constexpr uint8_t PIN_HOME_X = 9;   // X- end-stop header
constexpr uint8_t PIN_HOME_Y = 10;  // Y- end-stop header
constexpr uint8_t PIN_PROBE = 11;   // Z- end-stop header
constexpr uint8_t PIN_MICROSTEP_MS2 = 12;  // SpnEn
constexpr uint8_t PIN_MICROSTEP_MS3 = 13;  // SpnDir

constexpr bool MOTOR_A_DIRECTION_INVERTED = false;
constexpr bool MOTOR_B_DIRECTION_INVERTED = false;
// D8 is the shield's ENABLE net. On the CNC Shield V3.00 it connects DIRECTLY
// to every A4988 ENABLE pin (no inverter) and R1 (10K) pulls the net to 5 V,
// so the net idles high and the drivers are OFF unless D8 is pulled LOW
// (A4988 ENABLE is active-low). grbl 0.8, which this shield is built for,
// writes D8 LOW to enable (st_wake_up) and HIGH to disable (st_go_idle).
// Verified against the Protoneer V3.00 schematic and empirically on this
// machine: old firmware left D8 LOW and the motors moved; after this constant
// was set HIGH the motors went completely dead (no holding torque).
constexpr uint8_t DRIVER_ENABLE_ACTIVE_LEVEL = LOW;

// Existing switches and the temporary button probe close to ground.
constexpr uint8_t HOME_SWITCH_ACTIVE_LEVEL = LOW;
constexpr uint8_t PROBE_ACTIVE_LEVEL = LOW;

constexpr uint32_t SERIAL_BAUD = 115200;
constexpr size_t SERIAL_LINE_MAX = 96;

constexpr float X_MAX_MM = 400.0f;
constexpr float Y_MAX_MM = 320.0f;
// Canonical position units are 1/16 microsteps. The recovered calibration was
// 40.4 pulses/mm at 1/8, hence 80.8 base units/mm at 1/16.
constexpr float BASE_UNITS_PER_MM = 80.8f;

// Pen-up moves always request the coarsest electrically compatible mode.
// Pen-down lines use their length as a useful proxy: long G1 segments are
// straight features, while curves and detailed artwork arrive as short G1s.
constexpr float DRAW_FULL_STEP_MIN_MM = 30.0f;
constexpr float DRAW_HALF_STEP_MIN_MM = 15.0f;
constexpr float DRAW_QUARTER_STEP_MIN_MM = 7.0f;
constexpr float DRAW_EIGHTH_STEP_MIN_MM = 2.0f;

constexpr float TRAVEL_FEED_MM_MIN = 2000.0f;
constexpr float DRAW_FEED_MM_MIN = 800.0f;
constexpr float HOME_SEEK_FEED_MM_MIN = 600.0f;
constexpr float HOME_LATCH_FEED_MM_MIN = 150.0f;
constexpr float MAX_FEED_MM_MIN = TRAVEL_FEED_MM_MIN;
constexpr float ACCELERATION_MM_S2 = 200.0f;
constexpr float MIN_RAMP_SPEED_MM_S = 2.0f;

constexpr uint16_t STEP_PULSE_HIGH_US = 3;
constexpr float HOME_SEARCH_MARGIN_MM = 25.0f;
constexpr float HOME_BACKOFF_MM = 3.0f;
constexpr float HOME_FINAL_RELEASE_MM = 1.0f;
constexpr uint16_t SWITCH_DEBOUNCE_MS = 8;

// The old sketch and recovered map disagree about absolute servo direction.
// Keep this false until M280 has been used to find safe values, then edit the
// pulse constants and safety bounds below, then set PEN_CALIBRATED to true.
// Calibrated on-device: 500 us = tip touching paper (servo at its lowest),
// 1000 us = raised with good clearance. Verified visually during a full
// pulse sweep after adjusting the pen holder.
constexpr bool PEN_CALIBRATED = true;
constexpr int PEN_UP_US = 1500;
constexpr int PEN_DOWN_CENTER_US = 500;
constexpr int PEN_PRESSURE_OFFSET_US = 0;
constexpr int SERVO_SAFE_MIN_US = 500;
constexpr int SERVO_SAFE_MAX_US = 2200;
constexpr uint16_t SERVO_SETTLE_MS = 250;

}  // namespace drawbot::config

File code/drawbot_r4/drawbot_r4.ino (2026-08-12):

#include "command_processor.h"
#include "config.h"
#include "gcode_parser.h"
#include "motion_controller.h"
#include "pen_controller.h"
#include "serial_line_reader.h"

#include <ArduinoBLE.h>

drawbot::MotionController motion;
drawbot::PenController pen;
drawbot::CommandProcessor commands(motion, pen);
drawbot::SerialLineReader line_reader;

// Nordic UART Service (NUS) — the standard BLE serial profile.
// macOS pairs and creates a virtual serial port automatically.
static constexpr const char* BLE_SERVICE_UUID = "6E400001-B5A3-F393-E0A9-E50E24DCCA9E";
static constexpr const char* BLE_TX_CHAR_UUID = "6E400002-B5A3-F393-E0A9-E50E24DCCA9E";
static constexpr const char* BLE_RX_CHAR_UUID = "6E400003-B5A3-F393-E0A9-E50E24DCCA9E";

BLEService bleService(BLE_SERVICE_UUID);
BLECharacteristic bleTxChar(BLE_TX_CHAR_UUID, BLERead | BLENotify, 20);
BLECharacteristic bleRxChar(BLE_RX_CHAR_UUID, BLEWrite, 20);

class BlePrint : public Print {
public:
  size_t write(uint8_t c) override {
    if (pos_ < sizeof(buf_) - 1) buf_[pos_++] = c;
    return 1;
  }
  void flush() {
    uint8_t* p = (uint8_t*)buf_;
    while (pos_ > 20) {
      bleTxChar.writeValue(p, 20);
      p += 20;
      pos_ -= 20;
    }
    if (pos_ > 0) {
      bleTxChar.writeValue(p, pos_);
      pos_ = 0;
    }
  }
private:
  char buf_[128];
  size_t pos_ = 0;
};

BlePrint bleOut;

void setup() {
  Serial.begin(drawbot::config::SERIAL_BAUD);
  const uint32_t wait_started = millis();
  while (!Serial && millis() - wait_started < 5000U) {
  }

  motion.begin();
  motion.setIdleCallback([] { BLE.poll(); });
  pen.begin();

  if (!BLE.begin()) {
    Serial.println(F("ble: init failed"));
  } else {
    BLE.setLocalName("Drawbot");
    BLE.setAdvertisedService(bleService);
    bleService.addCharacteristic(bleTxChar);
    bleService.addCharacteristic(bleRxChar);
    BLE.addService(bleService);
    BLE.advertise();
  }

  Serial.println(F("ready"));
}

static drawbot::LineReadStatus pollBle() {
  if (!bleRxChar.written()) return drawbot::LineReadStatus::kNone;
  int len = bleRxChar.valueLength();
  const uint8_t* buf = bleRxChar.value();
  for (int i = 0; i < len; i++) {
    drawbot::LineReadStatus s = line_reader.feed((char)buf[i]);
    if (s != drawbot::LineReadStatus::kNone) return s;
  }
  return drawbot::LineReadStatus::kNone;
}

void loop() {
  BLE.poll();
  bool ble_connected = BLE.connected();

  drawbot::LineReadStatus line_status;
  if (Serial.available() > 0) {
    line_status = line_reader.poll(Serial);
  } else {
    line_status = pollBle();
  }
  if (line_status == drawbot::LineReadStatus::kNone) return;
  if (line_status == drawbot::LineReadStatus::kOverflow) {
    pen.forceSafeUp();
    Serial.println(F("error: line is too long"));
    if (ble_connected) { bleOut.print("error: line is too long\n"); bleOut.flush(); }
    return;
  }

  drawbot::GcodeCommand command;
  const drawbot::ParseStatus parse_status =
      drawbot::parseGcodeLine(line_reader.line(), command);
  if (parse_status == drawbot::ParseStatus::kEmpty) return;
  if (parse_status != drawbot::ParseStatus::kOk) {
    pen.forceSafeUp();
    Serial.print(F("error: "));
    Serial.println(drawbot::parseStatusMessage(parse_status));
    if (ble_connected) { bleOut.print("error: "); bleOut.println(drawbot::parseStatusMessage(parse_status)); bleOut.flush(); }
    return;
  }

  char error[112];
  if (ble_connected) {
    bleOut.flush();
    if (commands.execute(command, bleOut, error, sizeof(error))) {
      bleOut.println("ok");
    } else {
      pen.forceSafeUp();
      bleOut.print("error: ");
      bleOut.println(error);
    }
    bleOut.flush();
  } else {
    if (commands.execute(command, Serial, error, sizeof(error))) {
      Serial.println(F("ok"));
    } else {
      pen.forceSafeUp();
      Serial.print(F("error: "));
      Serial.println(error);
    }
  }
}

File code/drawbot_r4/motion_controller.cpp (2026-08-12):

#include "motion_controller.h"

#include <math.h>
#include <stdlib.h>

#include "config.h"
#include "corexy_math.h"
#include "dda_math.h"
#include "pen_controller.h"
#include "workspace_math.h"

namespace drawbot {
namespace {

int32_t absoluteSteps(int32_t value) { return value < 0 ? -value : value; }

int signOf(int32_t value) {
  if (value > 0) return 1;
  if (value < 0) return -1;
  return 0;
}

}  // namespace

const char* motionStatusMessage(MotionStatus status) {
  switch (status) {
    case MotionStatus::kOk:
      return "ok";
    case MotionStatus::kNotHomed:
      return "machine is not homed; run G28";
    case MotionStatus::kOutsideWorkspace:
      return "target is outside the 0..400 by 0..320 mm workspace";
    case MotionStatus::kInvalidFeed:
      return "feed must be greater than zero and within the configured limit";
    case MotionStatus::kUnexpectedHomeSwitch:
      return "unexpected home switch activation";
    case MotionStatus::kHomeSwitchStuck:
      return "home switch did not release";
    case MotionStatus::kHomeTimeout:
      return "home switch was not reached before the travel limit";
  }
  return "motion failure";
}

void MotionController::begin() {
  // Establish safe output levels. pinMode(OUTPUT) must come FIRST on the
  // Uno R4: calling it after digitalWrite() resets the output data register
  // and clobbers the just-written value (verified empirically).
  pinMode(config::PIN_MOTOR_A_STEP, OUTPUT);
  pinMode(config::PIN_MOTOR_B_STEP, OUTPUT);
  pinMode(config::PIN_MOTOR_A_DIR, OUTPUT);
  pinMode(config::PIN_MOTOR_B_DIR, OUTPUT);
  pinMode(config::PIN_MICROSTEP_MS1, OUTPUT);
  pinMode(config::PIN_MICROSTEP_MS2, OUTPUT);
  pinMode(config::PIN_MICROSTEP_MS3, OUTPUT);
  pinMode(config::PIN_DRIVER_ENABLE, OUTPUT);
  pinMode(config::PIN_HOME_X, INPUT_PULLUP);
  pinMode(config::PIN_HOME_Y, INPUT_PULLUP);
  pinMode(config::PIN_PROBE, INPUT_PULLUP);

  digitalWrite(config::PIN_MOTOR_A_STEP, LOW);
  digitalWrite(config::PIN_MOTOR_B_STEP, LOW);
  digitalWrite(config::PIN_MICROSTEP_MS1, LOW);
  digitalWrite(config::PIN_MICROSTEP_MS2, LOW);
  digitalWrite(config::PIN_MICROSTEP_MS3, LOW);
  digitalWrite(config::PIN_DRIVER_ENABLE,
               config::DRIVER_ENABLE_ACTIVE_LEVEL == LOW ? HIGH : LOW);
  digitalWrite(config::PIN_MOTOR_A_DIR, LOW);
  digitalWrite(config::PIN_MOTOR_B_DIR, LOW);

  setMicrostepMode(MicrostepMode::kFull);
  disableDrivers();
}

void MotionController::enableDrivers() {
  pinMode(config::PIN_DRIVER_ENABLE, OUTPUT);
  digitalWrite(config::PIN_DRIVER_ENABLE, config::DRIVER_ENABLE_ACTIVE_LEVEL);
  drivers_enabled_ = true;
  delay(2);
}

void MotionController::disableDrivers() {
  pinMode(config::PIN_DRIVER_ENABLE, OUTPUT);
  digitalWrite(config::PIN_DRIVER_ENABLE,
               config::DRIVER_ENABLE_ACTIVE_LEVEL == LOW ? HIGH : LOW);
  drivers_enabled_ = false;
  homed_ = false;
}

PositionMm MotionController::positionMm() const {
  return {position_units_.x / config::BASE_UNITS_PER_MM,
          position_units_.y / config::BASE_UNITS_PER_MM};
}

bool MotionController::xHomeActive() const {
  return digitalRead(config::PIN_HOME_X) == config::HOME_SWITCH_ACTIVE_LEVEL;
}

bool MotionController::yHomeActive() const {
  return digitalRead(config::PIN_HOME_Y) == config::HOME_SWITCH_ACTIVE_LEVEL;
}

bool MotionController::probeActive() const {
  return digitalRead(config::PIN_PROBE) == config::PROBE_ACTIVE_LEVEL;
}

void MotionController::setMicrostepMode(MicrostepMode mode) {
  bool ms1 = false;
  bool ms2 = false;
  bool ms3 = false;
  switch (mode) {
    case MicrostepMode::kFull:
      break;
    case MicrostepMode::kHalf:
      ms1 = true;
      break;
    case MicrostepMode::kQuarter:
      ms2 = true;
      break;
    case MicrostepMode::kEighth:
      ms1 = true;
      ms2 = true;
      break;
    case MicrostepMode::kSixteenth:
      ms1 = true;
      ms2 = true;
      ms3 = true;
      break;
  }
  pinMode(config::PIN_MICROSTEP_MS1, OUTPUT);
  digitalWrite(config::PIN_MICROSTEP_MS1, ms1 ? HIGH : LOW);
  pinMode(config::PIN_MICROSTEP_MS2, OUTPUT);
  digitalWrite(config::PIN_MICROSTEP_MS2, ms2 ? HIGH : LOW);
  pinMode(config::PIN_MICROSTEP_MS3, OUTPUT);
  digitalWrite(config::PIN_MICROSTEP_MS3, ms3 ? HIGH : LOW);
  microstep_mode_ = mode;
  delayMicroseconds(2);
}

MicrostepMode MotionController::preferredMode(float path_mm,
                                              bool pen_down) const {
  (void)path_mm;
  (void)pen_down;
  // Forced to 1/16 microstepping: positions are tracked in 1/16-step base
  // units and the recovered calibration (40.4 pulses/mm at 1/8) is only
  // consistent at 80.8 base units/mm, i.e. 1/16 stepping.
  // NOTE: the old claim that MS3/D13 must stay HIGH to release an A4988
  // "RESET rail" on this shield is refuted — the official Protoneer V3.00
  // design has no D13-to-RESET connection (there is no R10); D12/D13 are the
  // SpnEn/SpnDir headers. MS pins only select stepping resolution; they
  // cannot disable the drivers. If 1/16 stepping is ever verified missing on
  // the actual MS pads, re-tune BASE_UNITS_PER_MM instead of reviving that
  // theory.
  return MicrostepMode::kSixteenth;
}

int32_t MotionController::pulsesForDistance(float distance_mm,
                                            MicrostepMode mode) const {
  const float pulses_per_mm =
      config::BASE_UNITS_PER_MM / baseUnitsPerPulse(mode);
  return static_cast<int32_t>(ceilf(distance_mm * pulses_per_mm));
}

uint32_t MotionController::homingPeriodUs(float feed_mm_min,
                                          MicrostepMode mode) const {
  const float pulses_per_second =
      feed_mm_min * config::BASE_UNITS_PER_MM /
      (60.0f * baseUnitsPerPulse(mode));
  return static_cast<uint32_t>(lroundf(1000000.0f / pulses_per_second));
}

void MotionController::delayMicrosecondsLong(uint32_t duration_us) const {
  while (duration_us > 16000U) {
    delayMicroseconds(16000U);
    duration_us -= 16000U;
  }
  if (duration_us > 0U) delayMicroseconds(duration_us);
}

void MotionController::setMotorDirections(int direction_a, int direction_b) {
  const bool a_positive = direction_a >= 0;
  const bool b_positive = direction_b >= 0;
  pinMode(config::PIN_MOTOR_A_DIR, OUTPUT);
  digitalWrite(config::PIN_MOTOR_A_DIR,
               (a_positive != config::MOTOR_A_DIRECTION_INVERTED) ? HIGH
                                                                  : LOW);
  pinMode(config::PIN_MOTOR_B_DIR, OUTPUT);
  digitalWrite(config::PIN_MOTOR_B_DIR,
               (b_positive != config::MOTOR_B_DIRECTION_INVERTED) ? HIGH
                                                                  : LOW);
}
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

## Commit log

2025-05-18 Create readme cad
2025-05-18 WHY DOES IT NEED TO BE A CSV
    [bom.csv]
2025-05-24 found much cheaper items, total is $50 less :)
    [bom.csv]
2025-05-24 move bom to main
    [bom.csv]
2025-06-29 find cheaper servo
    [bom.csv]
2025-07-23 Update bom.csv (added item, removed an item, recalculated costs, gremmer)
    [bom.csv]
2025-07-25 why do i need bom in root in csv ***and*** readme in markdown
2025-08-02 add step files for cad
    [gantrybase1.step, gantrybase2.step, idlercorner1.step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]
2026-02-04 upload updated cad, upoad code
    updated cad: top plate of toolhead
    code: arduino code recieving gcode from serial, python code sending gcode line by line.
    later: queue gcode, send in chunks for efficiency.
    [drawbot (1).stl, drawbot.kicad_pcb, drawbot.kicad_sch]
2026-02-04 add individual printed cad files
    [drawbot (4).stl, drawbot_full.stl, drawbot_gantryplate1.stl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]
2026-08-12 Commission the machine: Uno R4 firmware, tools, and docs
    - Add drawbot_r4 firmware (Uno R4 WiFi + CNC Shield V3.00) with the
    commissioned state: pen calibrated, manual homing (M50), fixed ENABLE
    polarity and CoreXY Y-sign convention
    - Add hardened BLE streamer with drop recovery and position
    reconciliation, stress-pattern generator, and probe/sweep tools
    - Add operational handoffs and current wiring/commissioning docs
    - Document the presentation workflow (cross-hatch pattern over BLE)
    [ble_test.py, command_processor.cpp, config.h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]
2026-08-12 Resolve merge of stream_gcode.py and drawbot_homing.ino (keep both sides)
    [altbom.csv, bom.csv, drawbot (4).stl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]
